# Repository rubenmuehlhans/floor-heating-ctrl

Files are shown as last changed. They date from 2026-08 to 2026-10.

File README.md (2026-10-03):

# Heizungssteuerung

Mehrere ESP32 im Haus, die zusammen eine Ölheizung überwachen und in Teilen
steuern. Jedes Gerät hat eine eigene Aufgabe, kennt die anderen über mDNS und
fragt bei ihnen ab, was es selbst nicht messen kann.

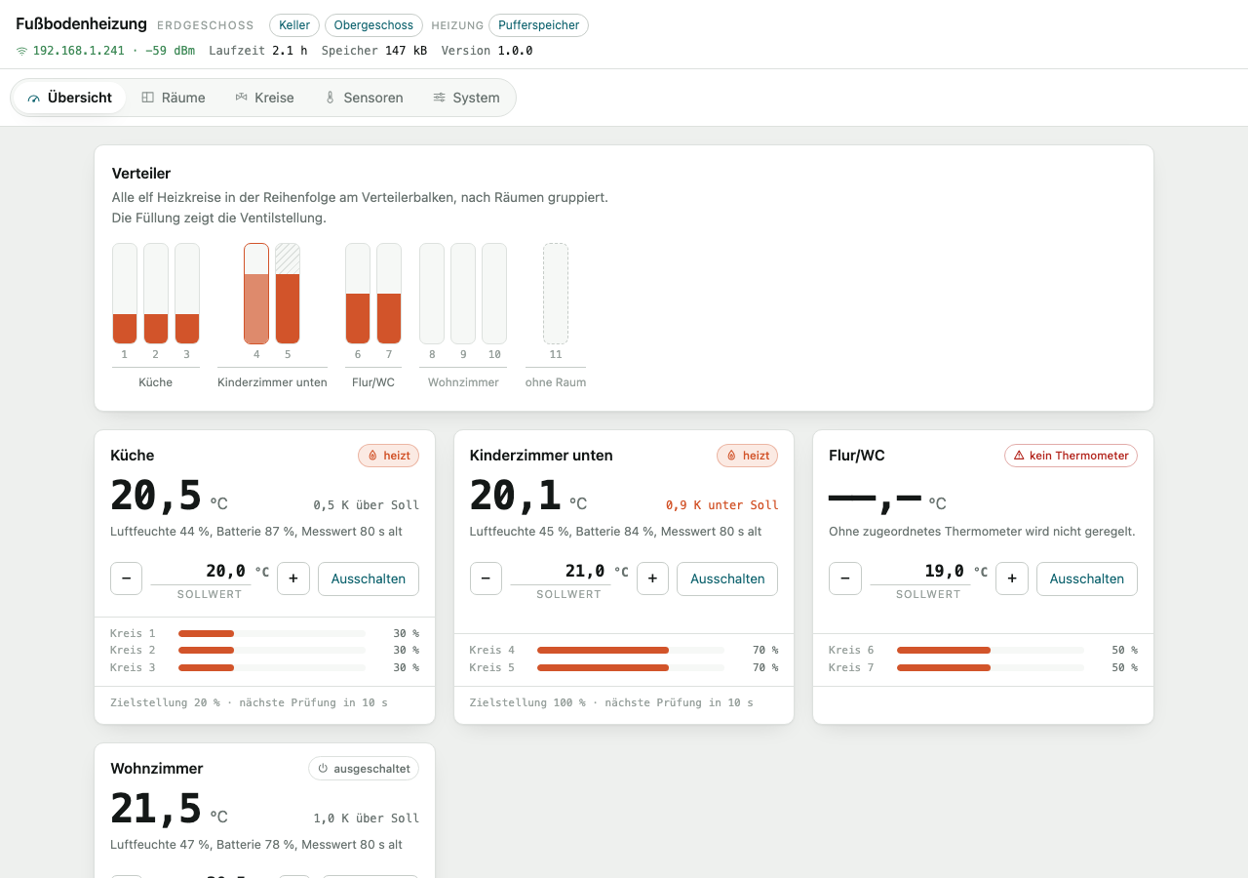
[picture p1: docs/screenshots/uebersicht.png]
Übersicht der Weboberfläche


## Was die Geräte tun

**Verteilerplatine**, je Etage eine. Sie fährt elf motorische Stellantriebe am
Heizkreisverteiler und regelt darüber die Raumtemperaturen. Die Antriebe haben
keine Endschalter; erkannt wird die Endlage an der Gegenspannung des
blockierenden Motors. Die Raumtemperaturen kommen über Bluetooth von
Xiaomi-Thermometern, die Außentemperatur von einem RuuviTag. Bedient wird über die Weboberfläche oder über Anzeige und
drei Tasten am Gehäuse. Einmal in der Woche fährt jeder Kreis einmal durch,
damit er über den Sommer nicht festsitzt. Wärmebedarf meldet sie nur für Räume,
die sie tatsächlich regelt; Kreise ohne Raum fährt sie zu.

**Gerät am Kessel.** Es misst Abgas, Kesselvorlauf und Kesselrücklauf. Am
Abgasfühler erkennt es, ob der Brenner läuft: Angelaufen ist er, wenn das Abgas
deutlich über einer gleitenden Bezugslinie liegt und um einen festen Ausschlag
über seinen letzten Tiefstwert gestiegen ist; aus ist er, wenn es um denselben
Ausschlag unter den Höchstwert der Fahrt fällt. Der Ausschlag greift auch bei
warmem Kessel, bei dem die Bezugslinie nicht mehr unterscheidet. Daraus
führt es Laufzeit, Startzahl und eine Verbrauchsschätzung. Es schaltet die
Kesselkreispumpe: Solange der Brenner läuft, läuft sie; danach entscheidet der
Abstand zwischen Kesselvorlauf und Speicher. Sie läuft, solange der Kessel
Wärme abgibt, und steht, sobald sie nur noch Wärme aus dem Speicher in den
Kessel tragen würde.

**Gerät am Pufferspeicher.** Es misst die Speichertemperatur und Vor- und
Rücklauf der Heizkreise, beurteilt daraus Ladezustand und Füllstand — dessen
Nullpunkt wird bei jedem Brennerstart nachgemessen — und schaltet die
Umwälzpumpen über Tasmota-Relais — ab, wenn kein Raum Wärme abruft, und
wöchentlich kurz an, damit sie nicht festsitzen. Ob ein Abnehmer da ist, fragt
es bei den Verteilerplatinen ab; den Brennerzustand holt es sich vom Gerät am
Kessel.

**Leitstand**, wahlweise. Ein M5Stack Core mit eigener Firmware
([`apps/station`](apps/station/)) zeigt den Zustand der Anlage auf seinem
Bildschirm, empfängt Funkthermometer und liefert die Außentemperatur an die
Heizungsgeräte; diese fragen ihn zuerst und erst danach die Verteilerplatinen.
Er regelt nichts. Aufzeichnung auf SD-Karte und HomeKit sind geplant, siehe
[Konzept Leitstand](docs/konzept-leitstand.md).

Welche Aufgabe ein Heizungsgerät übernimmt, ergibt sich allein aus den
zugeordneten Fühlerrollen. Beide Aufgaben sind dabei an eigene Messwerte
gebunden, nicht an solche aus dem Netz: Heizkreise lassen sich nur auf dem Gerät
mit dem Pufferfühler anlegen, die Kesselkreispumpe nur auf dem mit Kesselvor-
und -rücklauf. Mit fremden Werten zu schalten hieße, bei einem
Verbindungsabbruch ohne Grundlage dazustehen.

Kein Gerät ist auf ein anderes angewiesen. Fällt eines aus, arbeiten die
übrigen mit dem weiter, was sie selbst messen — die Pumpen laufen dann im
Zweifel, statt zu stehen.

**Aus dem laufenden Betrieb** entstehen zwei knappe Protokolle im Flash: je
abgeschlossener Ladung ein Satz, je Tag ein Satz. Daraus rechnet das Gerät zwei
Kennzahlen, die man sonst schätzt — den Wärmebedarf des Hauses je Heizgradtag
und den Grundverbrauch für Warmwasser — und meldet einen Tag, der deutlich über
dieser Linie liegt. Der Abstand zwischen Abgas- und Kesselvorlaufhöchstwert je
Ladung zeigt, ob der Wärmetauscher verrußt. Dazu kommen Plausibilitätsprüfungen
der Fühler, die Erkennung von Warmwasser, das bei stehender Pumpe in den
Kesselrücklauf strömt, und die Zählung der Warmwasserzapfungen. Alle Verfahren
melden, sie greifen nicht ein.

## Was daraus entsteht

Jedes Gerät bringt seine eigene Weboberfläche mit; eingerichtet wird alles
dort, ohne Übersetzen und ohne Konfigurationsdatei. An Home Assistant sind die
Geräte auf zwei Wegen anzubinden, einzeln oder gemeinsam: über MQTT-Discovery
oder über eine mitgelieferte Integration, die sie unmittelbar über HTTP
anspricht.

Der Quelltextbestand enthält neben der Firmware die Fertigungsdaten der Platine
([`board/`](board/)) und die Konstruktion des Gehäuses ([`case/`](case/)).

## Einordnung

Dies ist ein privates Bastelprojekt für die eigene Heizungsanlage. Es entsteht
in der Freizeit; eine laufende Betreuung, Unterstützung bei der Nachnutzung
oder Bearbeitung von Anfragen wird nicht zugesagt.

Das Projekt steht in keiner Verbindung zu einem Hersteller und implementiert
kein Funkprotokoll: Die Antriebe werden über eigene H-Brücken elektrisch
angesteuert, also durch Anlegen der Motorspannung. Verwendete
Produktbezeichnungen dienen allein der Angabe, welche Bauteile verbaut sind.

## Herkunft

Der Grundgedanke der Schaltung — Endlagenerkennung über die Gegenspannung,
Kanalauswahl über Schieberegister — und das Regelgesetz in
[`components/roomctrl`](components/roomctrl/) gehen auf
[floor-heating-controller](https://github.com/nliaudat/floor-heating-controller)
von nliaudat zurück, veröffentlicht unter der GPL-3.0. Dieser Bestand folgt ihr
darin; siehe [Lizenz](#lizenz).

## Inhalt

- [Was die Geräte tun](#was-die-geräte-tun)
- [Herkunft](#herkunft)
- [Dokumentation](#dokumentation)
- [Voraussetzungen](#voraussetzungen)
- [Hardware](#hardware)
- [Übersetzen und Einspielen](#übersetzen-und-einspielen)
- [Erste Inbetriebnahme](#erste-inbetriebnahme)
- [Weboberfläche](#weboberfläche)
- [Home Assistant](#home-assistant)
- [Funktionsweise](#funktionsweise)
- [Vorgabewerte](#vorgabewerte)
- [Fehlersuche](#fehlersuche)
- [Aufbau des Quelltextbestands](#aufbau-des-quelltextbestands)
- [Entwicklung ohne Hardware](#entwicklung-ohne-hardware)
- [Prüfungen](#prüfungen)
- [Stand der Erprobung](#stand-der-erprobung)
- [Offene Punkte](#offene-punkte)
- [Geplante Erweiterungen](#geplante-erweiterungen)
- [Fremdkomponenten](#fremdkomponenten)
- [Lizenz](#lizenz)
- [Marken](#marken)

## Dokumentation

| Dokument | Inhalt |
|---|---|
| [Benutzerhandbuch](docs/handbuch.md) | Bedienung, Einrichtung, Wartung und Fehlersuche — mit Aufnahmen beider Oberflächen |
| [Konzept: Wärmeerzeugung und Pumpensteuerung](docs/konzept-waermeerzeuger.md) | Messstellen, Brennererkennung, Ladezustand, Pumpenlogik |
| [Umbau auf zwei Anwendungen](docs/umbau-projektstruktur.md) | Aufteilung des Projekts und gemeinsame Komponenten |
| [Konzept: Auswertung der Anlage](docs/konzept-auswertung.md) | Anomalien und Wirkungsgrad aus den erfassten Daten — Datengrundlage, Verfahren, Reihenfolge |
| [Änderungen](CHANGELOG.md) | was sich seit welcher Fassung geändert hat |

Diese Seite beschreibt Hardware, Aufbau und Funktionsweise. Wer die Geräte bedienen
oder einrichten will, findet das im [Handbuch](docs/handbuch.md).

## Voraussetzungen

- **Verteilerplatine.** Benötigt werden die Steuerplatine aus [`board/`](board/)
  und ein darauf gesteckter ESP32-DevKitC mit WROOM-32, dazu bis zu elf
  motorische Stellantriebe ohne Endschalter am Heizkreisverteiler.
- **Raumtemperatur.** Je Raum wird ein Xiaomi-Thermometer mit ATC- oder
  pvvx-Firmware benötigt, das seine Messwerte als Rundruf sendet.
- **Außentemperatur.** Wahlweise ein RuuviTag; er wird an einer
  Verteilerplatine zugeordnet und liefert zusätzlich Feuchte und Luftdruck.
- **Heizungsgeräte.** Für Kessel und Pufferspeicher genügt je ein
  ESP32-DevKitC ohne eigene Platine, dazu DS18B20 am 1-Wire-Bus. Zum Schalten
  der Pumpen kommen Tasmota-Relais hinzu.
- **Netz.** Alle Geräte brauchen ein WLAN-Netz. Ein MQTT-Broker ist möglich,
  aber nicht nötig: Die Geräte finden einander über mDNS, und Home Assistant
  lässt sich auch über die mitgelieferte Integration anbinden.
- **Entwicklungsumgebung.** Zum Übersetzen wird ESP-IDF v6.0.2 vorausgesetzt.
- **Arbeiten ohne Gerät.** Die Geräteattrappe benötigt Python 3, die
  Erzeugung der Aufnahmen zusätzlich Google Chrome und ImageMagick.

## Hardware

Dieser Abschnitt beschreibt die **Verteilerplatine**. Die Geräte an Kessel und
Pufferspeicher brauchen keine eigene Platine: dort genügt ein ESP32-DevKitC mit
DS18B20 am 1-Wire-Bus, ein Anschlusswiderstand nach 3,3 V und, am
Pufferspeicher, je Heizkreis ein Tasmota-Relais für die Umwälzpumpe. Welcher
Anschluss sich für den Bus eignet, steht im
[Handbuch](docs/handbuch.md#anschluss-des-busses).

Verbaut sind motorische Stellantriebe vom Typ **HmIP-VDMOT**. Sie haben keine
Endschalter; die Endlage ist daran zu erkennen, dass der Motor am Anschlag
blockiert und die Spannung über dem Messwiderstand deutlich steigt.

Die Steuerplatine ist in EasyEDA selbst entworfen, von Hand geroutet und bei
**JLCPCB** gefertigt. Sie trägt
keinen eigenen Mikrocontroller: Ein **ESP32-DevKitC** wird auf Buchsenleisten
gesteckt und lässt sich damit ohne Löten tauschen. Fertigungsdaten, Gerber und
Stückliste liegen in [`board/`](board/), das Druckgehäuse in
[`case/`](case/).

| Baugruppe | Umsetzung |
|---|---|
| Stellantriebe | 11 × motorisch, ohne Endschalter (HmIP-VDMOT) |
| Anschluss der Antriebe | 11 × 4P4C-Buchse (RJ11) an der Platinenkante |
| Ansteuerung | 11 × L9110s H-Brücke, bidirektional |
| Auswahl des Kreises | 3 × SN74HC595 Schieberegister über SPI2, 22 der 24 Ausgänge belegt |
| Endlagenerkennung | Messwiderstand je Messgruppe an ADC1, 6 Messgruppen, Dämpfung 6 dB |
| Anzeige | SSD1327, 128 × 128, 16 Graustufen, I²C |
| Bedienung am Gerät | 3 kapazitive Tasten: Sollwert −, Sollwert +, Raumwahl |
| Vorlauffühler | DS18B20 am 1-Wire-Bus, bis zu 8 Fühler, eigene 4P4C-Buchse |
| Schaltschrank-Klima | HDC1080, I²C |
| Stromversorgung | HLK-5M03, Netzanschluss über Klemme auf der Platine |
| Rechner | ESP32-DevKitC (WROOM-32) auf Sockel |

> Auf der Platine liegt Netzspannung. Der Netzbereich ist durch gefräste
> Trennschlitze abgegrenzt; Aufbau und Gehäuse sind in
> [`case/README.md`](case/README.md) beschrieben, einschließlich der dort
> genannten Einschränkungen zu Werkstoff und Zugentlastung.

### Anschlussbelegung

| Funktion | Pin |
|---|---|
| Schieberegister | DATA 16, CLK 5, LATCH 17, OE 18 |
| Gegenspannung, ADC1, Dämpfung 6 dB | 36, 39, 34, 35, 32, 33 |
| 1-Wire | 23 |
| I²C | SDA 21, SCL 22 |
| Tasten | 4 (−), 2 (+), 15 (Raumwahl) |

Die Zuordnung steht ausschließlich in
[`components/hw_map/`](components/hw_map/); alles andere arbeitet mit
Kreisnummern 1 bis 11 und Gruppennummern 0 bis 5.

### Messgruppen

Je zwei Heizkreise teilen sich einen Messeingang:

| Gruppe | ADC-Pin | Kreise |
|---|---|---|
| 1 | 36 | 1, 2 |
| 2 | 39 | 3, 4 |
| 3 | 34 | 5, 6 |
| 4 | 35 | 7, 8 |
| 5 | 32 | 9, 10 |
| 6 | 33 | 11 |

Daraus folgt die zentrale Betriebsregel: **Innerhalb einer Messgruppe fährt
immer nur ein Kreis.** Sonst liegt die Gegenspannung beider Motoren auf
demselben Eingang und die Endlage ließe sich keinem Antrieb mehr zuordnen.
Durchgesetzt wird das von der Gruppensperre in
[`apps/manifold/main/app_control.c`](apps/manifold/main/app_control.c).

## Übersetzen und Einspielen

Fertige Abbilder liegen bei den [Veröffentlichungen](https://github.com/rubenmuehlhans/floor-heating-ctrl/releases).
Wer nicht selbst übersetzen will, spielt sie über USB unmittelbar aus dem
Browser auf: **[Web-Flasher](https://rubenmuehlhans.github.io/floor-heating-ctrl/)**
(Chrome oder Edge; die Web-Serial-Schnittstelle gibt es in Firefox und Safari
nicht). Die Seite liegt im Zweig `gh-pages` und lädt nichts von fremden
Rechnern nach.

Zum Selbstübersetzen: Vorausgesetzt wird ESP-IDF v6.0.2. Das Repositorium enthält mehrere
Anwendungen, die sich `components/` teilen; gebaut wird deshalb mit `-C` aus
dem Verzeichnis der jeweiligen Anwendung. Die Verteiler-Firmware liegt unter
`apps/manifold`. Der Leitstand (`apps/station`) braucht zusätzlich das esp-homekit-sdk, das als
Untermodul unter `third_party/` eingebunden ist; nach dem Klonen einmal
`git submodule update --init`.

```bash
. ~/esp/esp-idf-6.0.2/export.sh && idf.py -C apps/manifold set-target esp32 && idf.py -C apps/manifold build
```

```bash
idf.py -C apps/manifold -p /dev/cu.usbserial-0001 flash monitor
```

Spätere Aktualisierungen laufen über die Weboberfläche (System → Firmware
aktualisieren) oder direkt:

```bash
curl -X POST --data-binary @apps/manifold/build/floor-heating-ctrl.bin http://<adresse>/api/ota
```

Die Firmware belegt rund 1,2 MB. Die Partitionstabelle sieht zwei
OTA-Bereiche zu je 1 966 080 Byte vor; rund 39 % bleiben frei. Eine frisch
eingespielte Firmware wird erst bestätigt, wenn Konfiguration, Ausgangsstufe,
Regelung und Weboberfläche angelaufen sind; andernfalls kehrt der Bootlader zur
vorherigen zurück.

## Erste Inbetriebnahme

1. Nach dem ersten Einspielen findet das Gerät kein WLAN und öffnet sofort
   einen Zugangspunkt `floor-heating-XXXX` mit dem Kennwort `fussboden`. Die
   vier Stellen sind die letzten beiden Bytes der MAC-Adresse.
2. Beim Verbinden öffnet sich das Einrichtungsportal von selbst (Captive
   Portal). Rufen Sie andernfalls `http://192.168.4.1` auf.
3. Wählen Sie das Netz aus, tragen Sie das Kennwort ein und speichern Sie. Der
   Zugangspunkt schließt sich, sobald die Verbindung steht und niemand mehr
   daran hängt.
4. Danach führt der Einrichtungsassistent in drei Schritten durch die Anlage:
   Bezeichnung der Etage, Räume mit ihren Heizkreisen, Thermometer je Raum. Er
   startet von selbst, solange keine Bezeichnung hinterlegt ist, und ist später
   über **System → Einrichtung erneut durchlaufen** wieder erreichbar. Die
   Thermometer erscheinen zur Auswahl, sobald ihr erster Rundruf empfangen
   wurde.
5. Starten Sie unter **Kreise** für jeden Kreis eine Messfahrt.
6. Lesen Sie unter **Sensoren** die Rohwerte der Tasten in Ruhe und bei
   Berührung ab und setzen Sie die Schwelle etwa mittig.
7. Tragen Sie unter **System** die MQTT-Verbindung ein, falls Home Assistant
   angebunden werden soll; ab Werk ist MQTT ausgeschaltet.

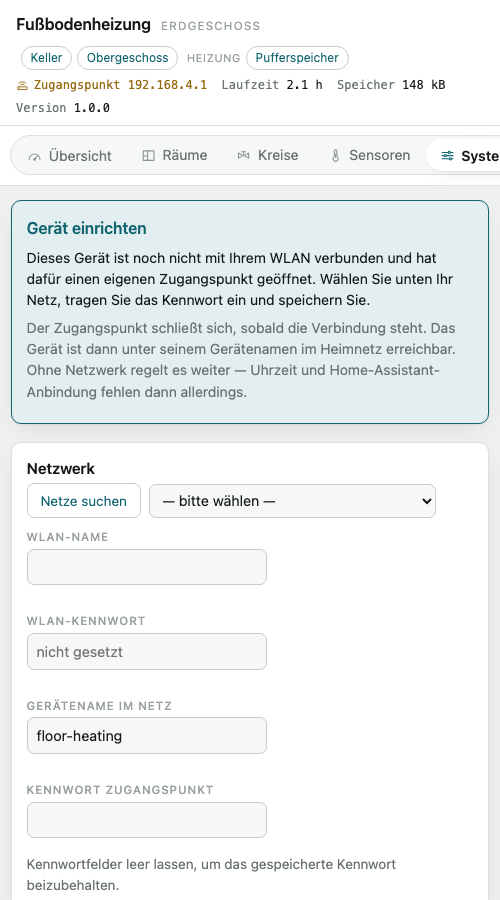
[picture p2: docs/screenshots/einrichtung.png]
Einrichtungsportal


## Weboberfläche

Räume, Kreiszuordnung, Thermometer und Regelparameter sind zur Laufzeit
änderbar. Die Weboberfläche liegt komprimiert im Programmabbild (rund 22 kB)
und lädt ohne Internetzugang.

| | |
|---|---|
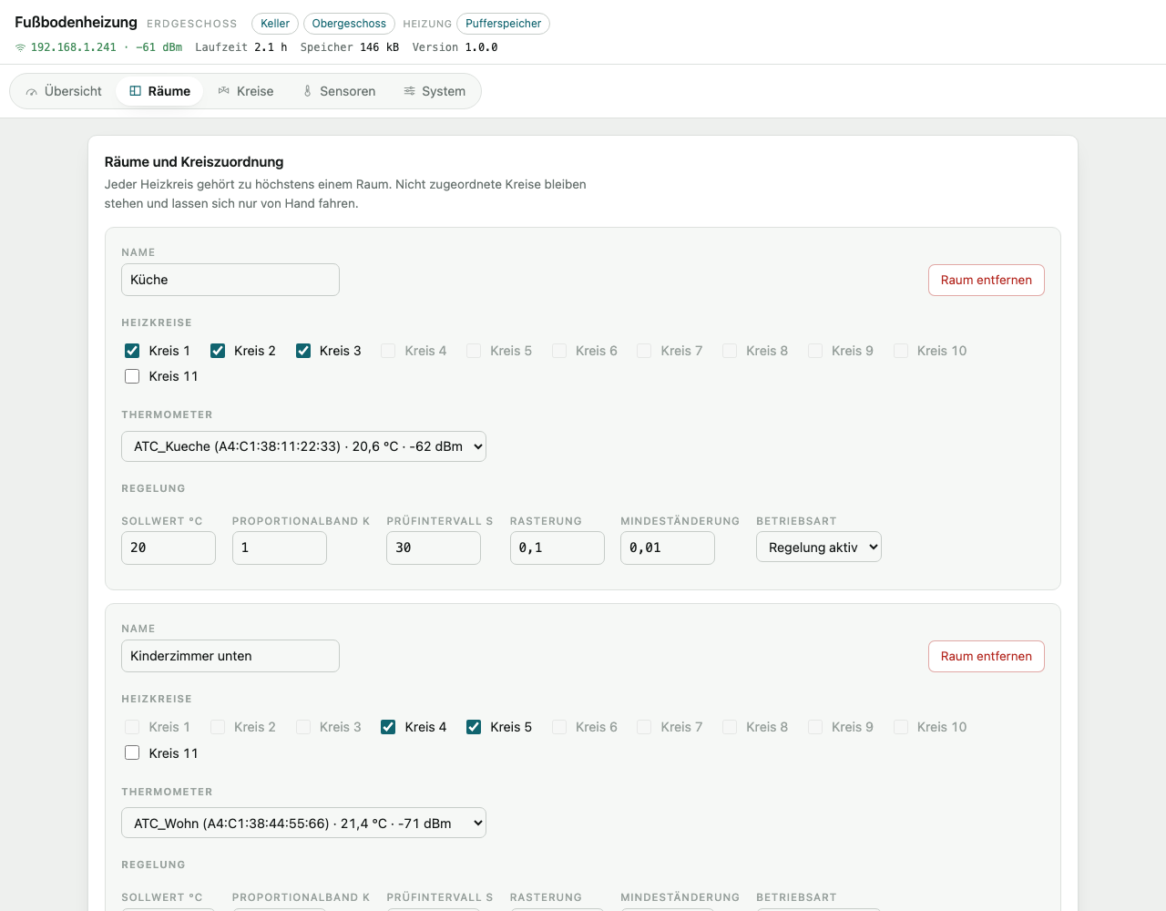
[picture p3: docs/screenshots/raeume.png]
Räume
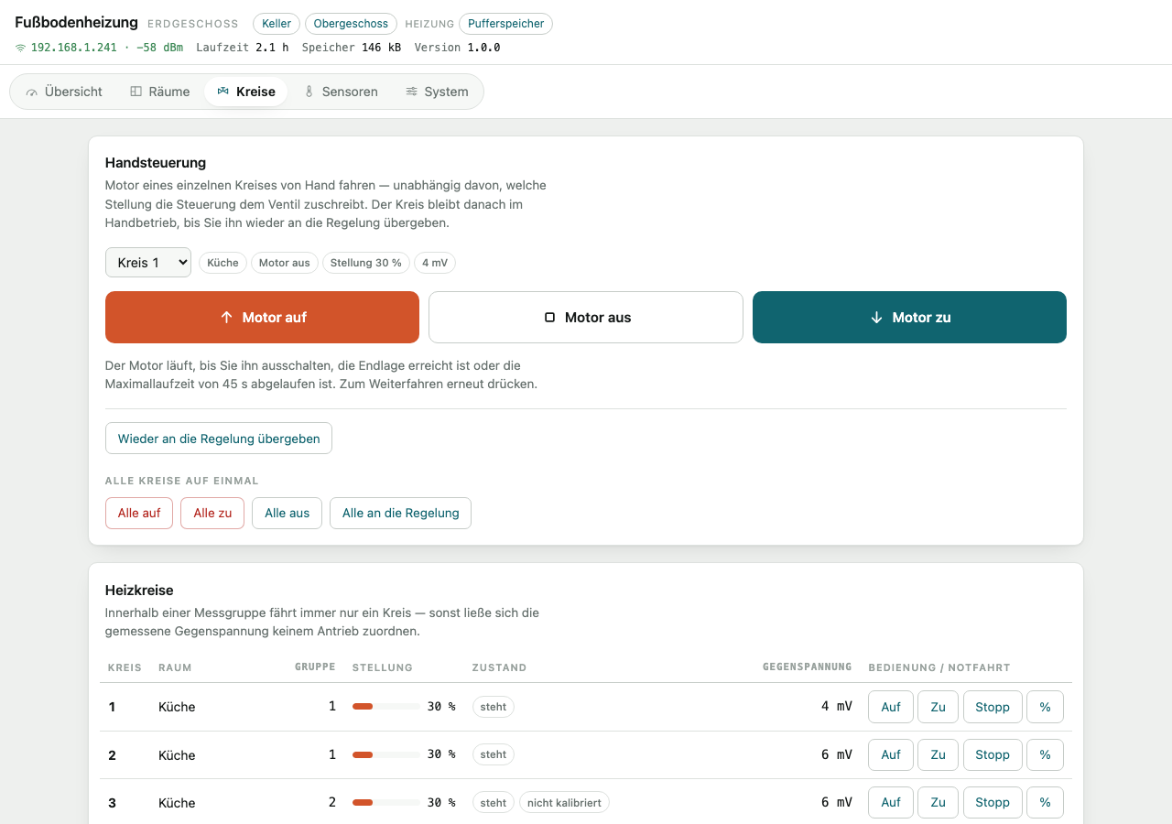
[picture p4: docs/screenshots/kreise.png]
Heizkreise
|  |  |
| **Räume** — Kreise zuordnen, Thermometer wählen, Regelparameter einstellen | **Kreise** — Zustand, Handsteuerung, Fahrzeiten und Schwellen |
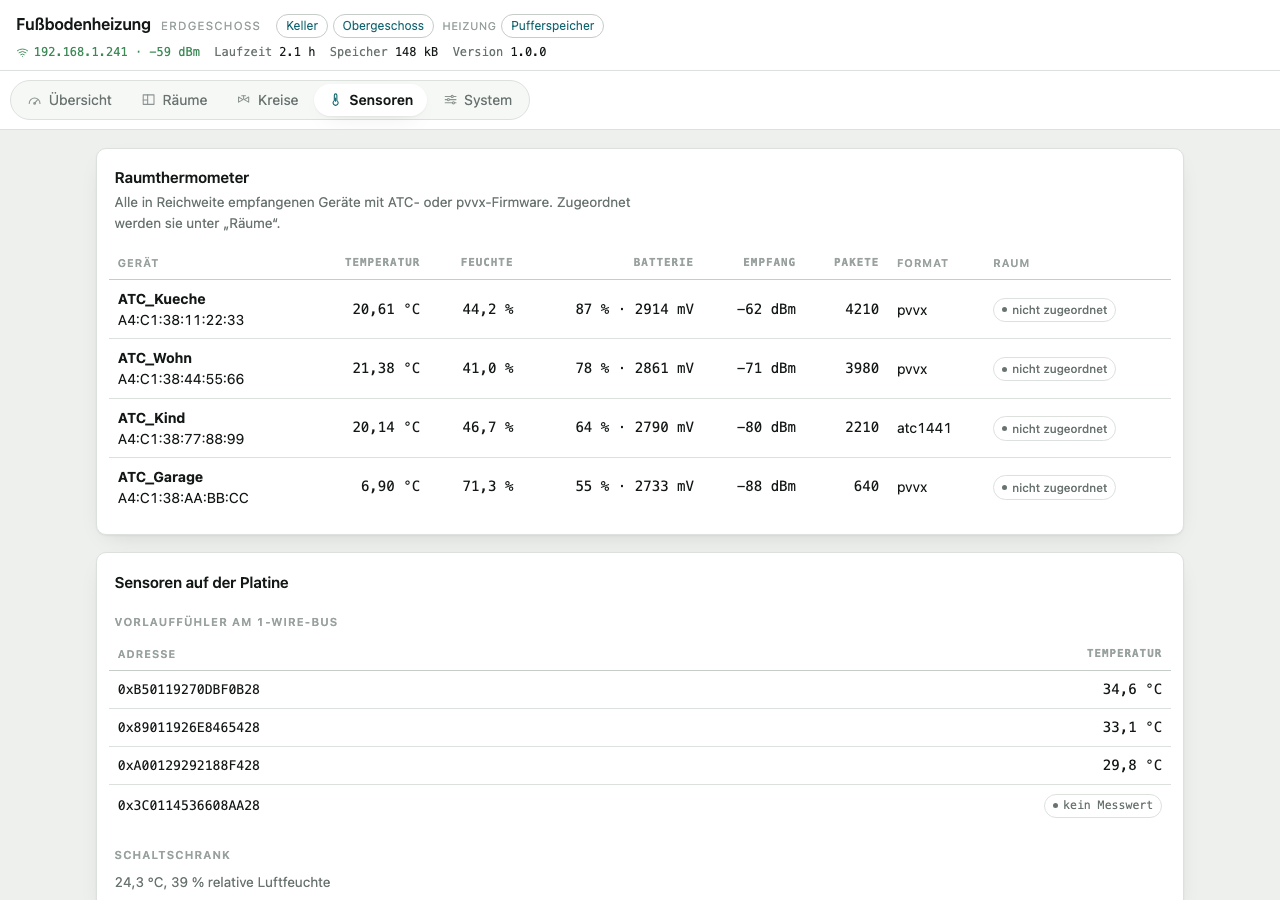
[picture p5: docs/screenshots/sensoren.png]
Sensoren
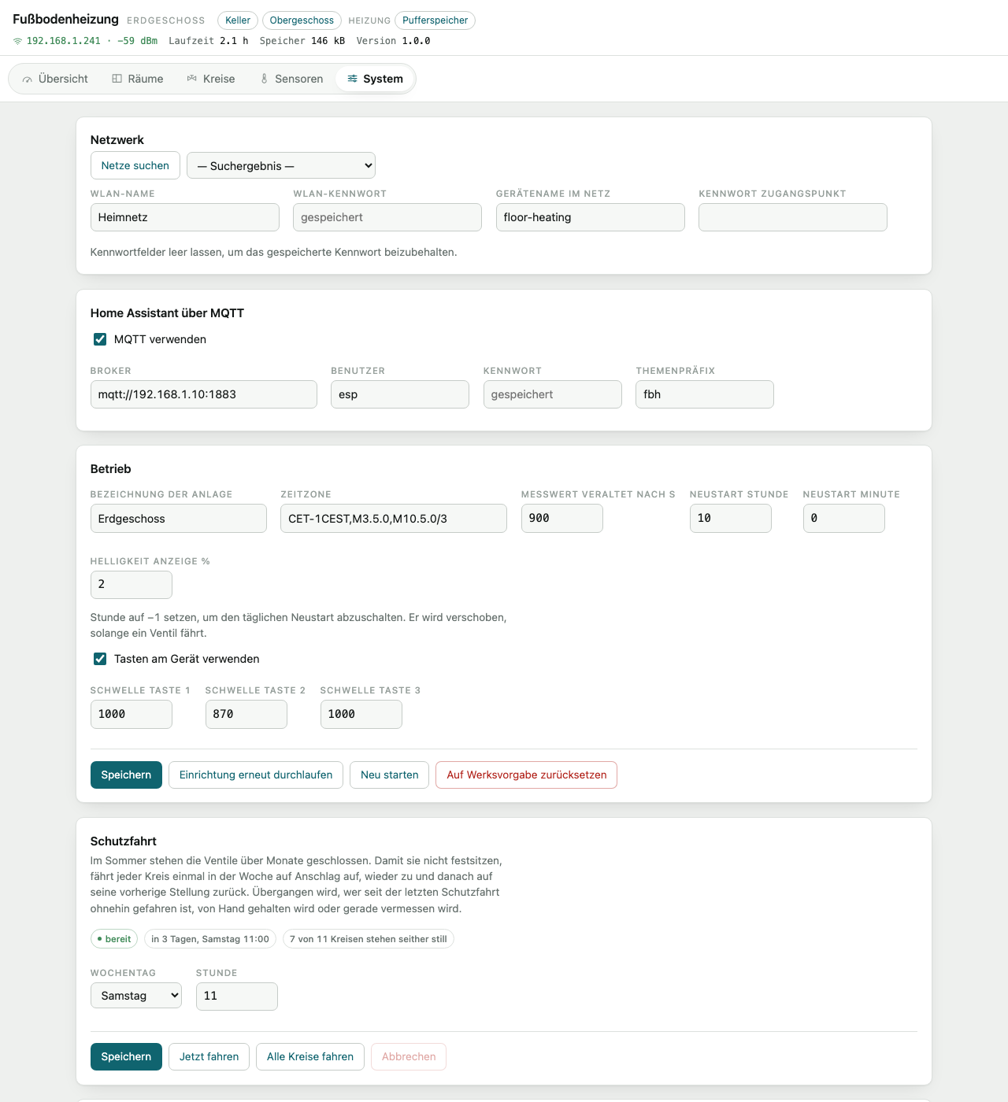
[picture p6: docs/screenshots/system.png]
System
|  |  |
| **Sensoren** — empfangene Thermometer, Vorlauffühler, Tastenabgleich | **System** — Netzwerk, MQTT, Betrieb, Firmware |

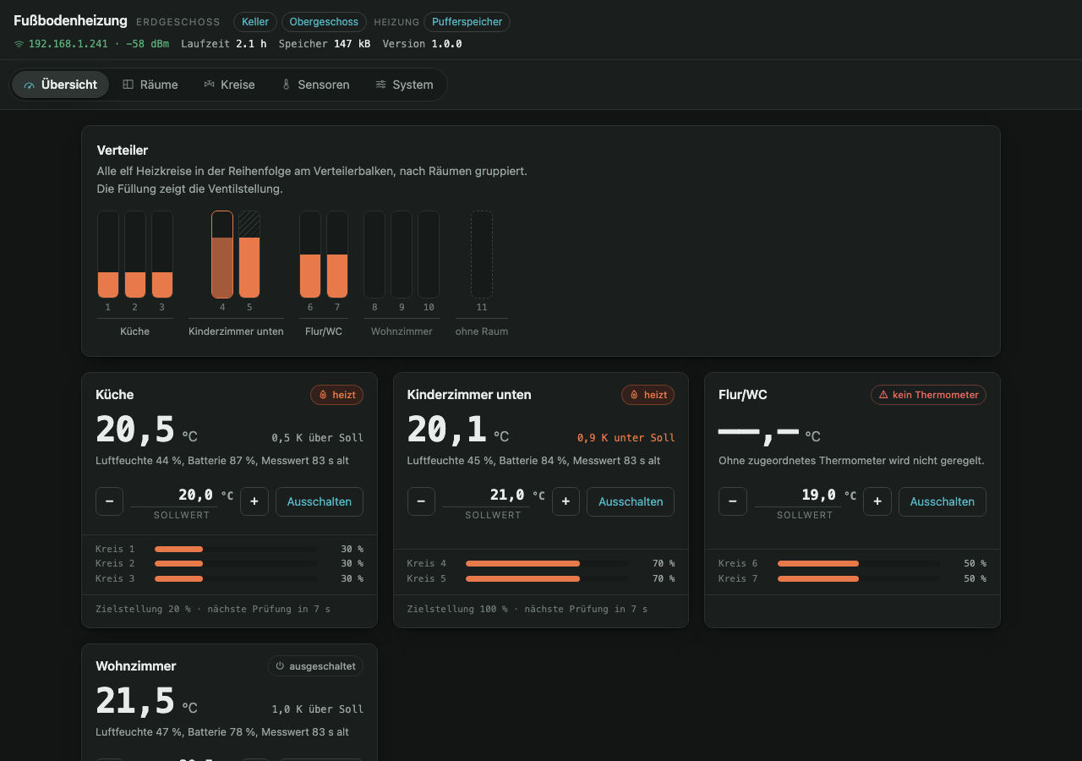
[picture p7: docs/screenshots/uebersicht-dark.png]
Dunkles Farbschema

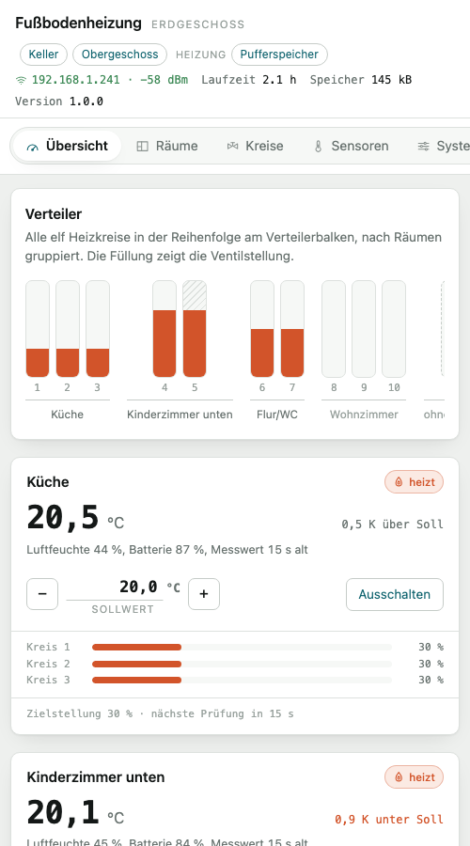
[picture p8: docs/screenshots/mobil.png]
Ansicht auf dem Telefon


### Abfragetakt

Die Seite fragt den Gerätezustand nicht in festem Takt ab, sondern richtet sich
danach, was sich tatsächlich ändert:

| Lage | Takt |
|---|---|
| ein Ventil fährt oder eine Messfahrt läuft | 1 s |
| Ruhezustand | 6 s |
| Seite im Hintergrund | keine Abfrage |
| Messreihe während einer Messfahrt | 400 ms |
| Liste der empfangenen Thermometer | 30 s |

`/api/state` gibt den Änderungszähler als ETag mit. Fragt die Seite mit
demselben Wert erneut an und fährt gerade kein Ventil, antwortet das Gerät mit
304 und erspart sich den Aufbau der rund 4 kB großen Antwort. Restzeiten,
Messwertalter und Laufzeit rechnet die Seite selbst weiter.

Fährt ein Kreis 20 % der Zeit, ergibt das rund 20 Zustandsabfragen je Minute;
Inhalt liefern davon nur die während der Fahrt und die nach einer Änderung.

## Home Assistant

Es gibt zwei Wege. Beide führen zu denselben Entitäten; sie schließen einander
nicht aus, sollten aber nicht gleichzeitig verwendet werden, weil sonst zwei
Wege dieselben Werte setzen.

### Eigene Integration

Unter [`custom_components/floor_heating/`](custom_components/floor_heating/)
liegt eine Integration, die unmittelbar mit dem Gerät spricht. Sie braucht
keinen MQTT-Broker und wird über HACS als benutzerdefiniertes Repository
hinzugefügt oder von Hand nach `config/custom_components/` kopiert. Eingerichtet
wird sie über **Einstellungen → Geräte & Dienste → Integration hinzufügen**;
gefragt wird nur nach der Adresse des Geräts.

Zusätzlich zu den Entitäten stellt sie fünf Dienste bereit, die sich in
Automatisierungen aufrufen lassen:

| Dienst | Wirkung |
|---|---|
| `floor_heating.calibrate` | Messfahrt für einen Kreis starten |
| `floor_heating.calibrate_accept` | Ergebnis der Messfahrt übernehmen |
| `floor_heating.calibrate_abort` | laufende Messfahrt abbrechen |
| `floor_heating.force` | Notfahrt auf, zu oder anhalten |
| `floor_heating.release` | Handbetrieb eines Kreises aufheben |

Der Zustand wird alle fünf Sekunden abgefragt. Da das Gerät seinen
Änderungszähler als ETag mitgibt, bleibt die Abfrage im Ruhezustand ohne
Inhalt (siehe [Abfragetakt](#abfragetakt)).

Ob Schnittstelle und Integration zueinander passen, prüft
`tools/check_api.py` ohne laufende Home-Assistant-Installation:

```bash
python3 tools/check_api.py 192.168.1.250
```

### MQTT-Discovery

Die Entitäten werden per MQTT-Discovery angemeldet und bei jeder
Konfigurationsänderung neu berechnet; entfallene Räume werden wieder entfernt.

| Typ | Umfang |
|---|---|
| `cover` | 11 Heizkreise mit Position, Öffnen/Schließen/Stopp |
| `climate` | je eingerichtetem Raum |
| `sensor`, je Raum | Temperatur, Luftfeuchte, Batterie des Thermometers, Zielstellung |
| `sensor`, Diagnose | 6 Messgruppen in mV, erkannte Vorlauffühler, Schaltschrankklima, Laufzeit, WLAN-Empfang, freier Speicher |
| `button` | Neustart, Regelung je Raum sofort auslösen |

Öffnen, Schließen und Stopp über die `cover`-Entitäten setzen den Halt des
Handbetriebs und bleiben damit stehen; eine gesetzte Position tut das nicht und
wird von der Regelung wieder überschrieben.

Die 22 einzelnen H-Brücken-Eingänge werden bewusst **nicht** exportiert, denn
direktes Schalten umginge Verriegelung und Gruppensperre.

## Funktionsweise

Dieser Abschnitt beschreibt die Verteilerplatine. Wie Brennererkennung,
Ladezustand und Pumpensteuerung arbeiten, steht im
[Konzept zur Wärmeerzeugung](docs/konzept-waermeerzeuger.md).

### Endlagenerkennung

Im Lauf zieht der Motor eine kleine Spannung über den Messwiderstand; erreicht
das Ventil den Anschlag, blockiert er und die Spannung steigt deutlich. Alle
sechs Messgruppen werden alle 50 ms abgetastet, ausgewertet wird ein gleitender
Median über fünf Werte. Erreicht er die Auslöseschwelle, gilt die Endlage als
erreicht und die Position wird auf 0 beziehungsweise 100 % gesetzt. Scharf ist
die Auswertung nur für die Messgruppe eines gerade fahrenden Kreises; die
Schwelle ist dann die des fahrenden Kreises.

Nach dem Anlauf gilt eine Sperrzeit von zwei Sekunden, in der die Meldung
verworfen wird, denn der Einschaltstrom sieht sonst wie ein Blockieren aus.
Bleibt die Endlage aus, beendet die Maximallaufzeit die Fahrt.

### Messfahrt zur Schwellwertermittlung

Die Auslöseschwelle hängt von Antrieb, Messwiderstand und Verkabelung ab.
Statt sie von Hand zu suchen, fährt die Messfahrt den Kreis einmal ganz zu und
einmal ganz auf und schreibt dabei den Spannungsverlauf mit. Das Blockieren
wird **relativ** zum gemessenen Fahrniveau erkannt; eine vorhandene Schwelle
geht nicht ein, sonst würde die Messfahrt ihr eigenes Ergebnis voraussetzen.

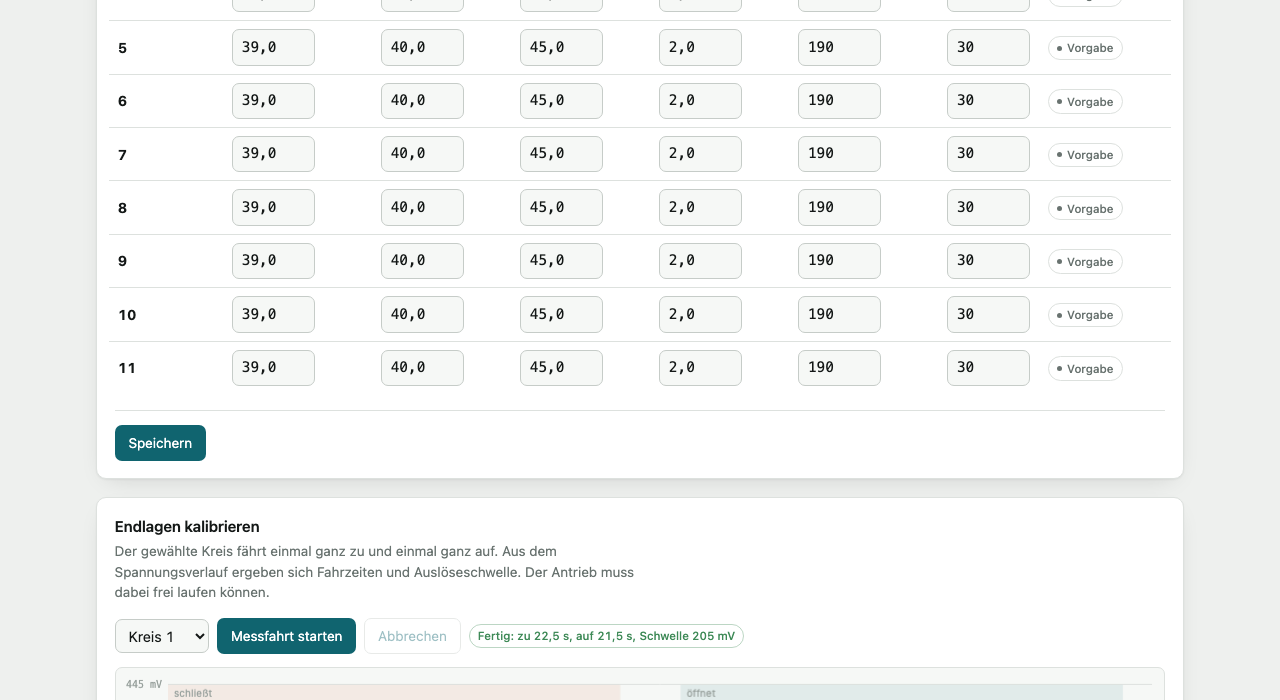
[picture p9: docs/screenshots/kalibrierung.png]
Ergebnis einer Messfahrt


Braun ist die Schließfahrt, blau die Öffnungsfahrt, dazwischen liegen drei
Sekunden Ruhe. Die beiden Spitzen sind die Anschläge. Aus dem Verlauf ergeben
sich Fahrzeiten, Maximallaufzeit (längste Fahrzeit plus rund 15 %),
Auslöseschwelle (Mitte zwischen Fahrniveau und niedrigerer Spitze) und
Hysterese; übernommen werden sie erst nach Bestätigung.

Wird in einer Fahrtrichtung keine Endlage erkannt, bricht die Messfahrt mit
einem Hinweis auf Verdrahtung und Messwiderstand ab.

### Handsteuerung und Notfahrt

Jeder Kreis lässt sich von Hand fahren, **unabhängig davon, welche Stellung
die Steuerung ihm zuschreibt**. Das ist kein gewöhnlicher Fahrbefehl:
`valve_goto` prüft die geschätzte Stellung und täte nichts, wenn das Ventil
bereits als offen gilt; bei unbekannter Stellung führe es sogar erst eine
Referenzfahrt gegen die untere Endlage aus, bei „auf“ also zunächst zu. Für
den Notfall ist beides falsch.

`valve_force` fährt deshalb ohne Stellungsvergleich bis zum Anschlag. Beendet
wird die Fahrt nur durch die Endlage, die Maximallaufzeit oder einen Halt. Über
`/api/channel/all/cmd` gilt der Befehl für alle elf Kreise zugleich.

Danach bleibt der Kreis im **Handbetrieb**: Die Regelung fasst ihn nicht mehr
an, bis er ausdrücklich wieder freigegeben wird. Ohne diesen Halt wäre eine
von Hand erzwungene Stellung beim nächsten Regeldurchlauf nach spätestens
einem Prüfintervall wieder verworfen. Denselben Halt setzt ein Stoppbefehl:
Von Hand angehalten bleibt von Hand angehalten. Die Freigabe erfolgt über den
Befehl „Automatik“, einzeln oder für alle Kreise; der zugehörige Raum wird
sofort neu bewertet, statt bis zum nächsten Prüfintervall zu warten.

Ein Fahrbefehl auf eine bestimmte Stellung setzt den Halt **nicht** — er wird
von der Regelung nach spätestens einem Prüfintervall überschrieben.

Die Gruppensperre gilt weiter: Fährt in derselben Messgruppe bereits ein
anderer Kreis, wartet der Befehl, bis sie frei ist.

### Regelung

Die Ventilstellung folgt der Regelabweichung proportional, über ein Band von
±1 K (Vorgabe) von ganz zu bis ganz auf, gerastert auf Zehntel:

```text
diff = soll − ist
pos  = runden(((diff / band) + 1) / 2 / raster) × raster,   begrenzt auf 0 … 1
gefahren wird, wenn |aktuell − pos| > Mindeständerung
```

Band, Rasterung, Mindeständerung und Prüfintervall sind je Raum einstellbar.
Der erste Regeldurchlauf findet erst 50 Sekunden nach dem Start statt, damit
Messwerte und Netzwerk eingelaufen sind. Die Ventilstellungen werden höchstens
einmal je Minute in den NVS geschrieben und beim Start wiederhergestellt.

### Raumtemperatur

Der ESP32 hört die Raumthermometer selbst mit: Xiaomi-Thermometer mit ATC- oder
pvvx-Firmware, RuuviTags und Thermometer mit BTHome senden ihre Messwerte als
Rundruf. Es wird keine Verbindung aufgebaut und nichts gesendet. Damit hängt die
Regelung nicht am Netzwerk. Verschlüsseltes BTHome, etwa vom Climate-Sat von
camperSense, liest der Verteiler mit dem Schlüssel des jeweiligen Geräts, den die
Oberfläche unter **Sensoren** entgegennimmt.

Bleibt ein Messwert länger als eingestellt aus (Vorgabe 900 s), setzt die
Regelung für diesen Raum aus und die Ventile bleiben stehen, statt mit einem
veralteten Wert weiterzuregeln. Dasselbe gilt, solange für einen Raum noch kein
Messwert eingegangen ist. Wärmebedarf meldet der Raum in dieser Zeit nicht.

## Vorgabewerte

Bis zur ersten Messfahrt und vor der Einrichtung gelten diese Werte. Sie
stammen aus dem Betrieb der Anlage. Die Tabelle gilt für die Verteilerplatine;
die Vorgaben der Heizungsgeräte und jede einzelne Einstellung beider Gerätetypen
mit ihrem zulässigen Bereich stehen im
[Handbuch](docs/handbuch.md#konfiguration-im-einzelnen).

| Größe | Vorgabe |
|---|---|
| Öffnungszeit / Schließzeit je Kreis | 39 s / 40 s |
| Maximallaufzeit je Kreis | 45 s |
| Auslöseschwelle / Hysterese | 190 mV / 30 mV |
| Sperrzeit nach dem Anlauf | 2 s |
| Solltemperatur je Raum | 20 °C |
| Proportionalband | 1,0 K |
| Rasterung / Mindeständerung | 0,1 / 0,01 |
| Prüfintervall | 30 s |
| Höchstalter eines Raummesswerts | 900 s |
| Täglicher Neustart | 10:00 Uhr, Zeitzone `CET-1CEST,M3.5.0,M10.5.0/3` |
| Gerätename | `floor-heating` |
| Kennwort des Einrichtungs-Zugangspunkts | `fussboden` |
| MQTT | ausgeschaltet, Präfix `fbh` |
| Tastenschwellen | 1000, 870, 1000 |

Ein täglicher Neustart wird verschoben, solange ein Stellantrieb fährt.

## Fehlersuche

Die folgenden Fälle ergeben sich aus dem beschriebenen Verhalten des Geräts.

| Beobachtung | Ursache | Abhilfe |
|---|---|---|
| Das Gerät verbindet sich nicht, ein Zugangspunkt `floor-heating-XXXX` erscheint | Es sind keine WLAN-Zugangsdaten hinterlegt | Über das Einrichtungsportal verbinden |
| Das Einrichtungsportal öffnet sich beim Verbinden nicht von selbst | Das Betriebssystem erkennt das Captive Portal nicht | `http://192.168.4.1` aufrufen |
| Ein Raum wird nicht geregelt, die Ventile stehen | Der Messwert ist älter als das eingestellte Höchstalter, oder es liegt noch keiner vor | Empfang unter **Sensoren** prüfen |
| Die Messfahrt bricht mit einem Hinweis ab | In einer Fahrtrichtung wurde keine Endlage erkannt | Verdrahtung und Messwiderstand prüfen |
| Ein Kreis folgt der Regelung nicht | Der Kreis steht im Handbetrieb | Befehl „Automatik“ für den Kreis oder für alle Kreise |
| Ein Fahrbefehl wird erst verzögert ausgeführt | In derselben Messgruppe fährt bereits ein anderer Kreis | Abwarten; die Gruppensperre gibt den Befehl frei |
| Die Tasten am Gehäuse lösen nicht aus | Die Tastenschwellen passen nicht zur Baugruppe | Rohwerte unter **Sensoren** ablesen, Schwelle mittig setzen |
| Nach einer Aktualisierung läuft wieder die vorherige Firmware | Die neue Fassung ist nicht vollständig angelaufen und wurde nicht bestätigt | Ursache über `idf.py monitor` suchen |

## Aufbau des Quelltextbestands

```text
apps/manifold/    Verteiler-Firmware
  main/
    main.c        Start der Bausteine
    app_control.c Ventilzustände, Gruppensperre, Raumregelung   ← Kern
    app_calib.c   Messfahrt und Auswertung der Schwellwerte
    app_web.c     HTTP-Server, JSON-Schnittstelle, Captive Portal, OTA
    app_mqtt.c    Home-Assistant-Discovery und Zustände
    app_ui.c      Anzeige und Tasten am Gerät
    www/            Oberfläche: kopf.html, rumpf.html und sources.txt
apps/heatsource/  Firmware der Heizungsgeräte (Kessel und Pufferspeicher)
  components/     eigene Konfiguration, verdrängt die gemeinsame
  main/           Fühlererfassung, Verlauf, Weboberfläche
www/stil.css      gemeinsames Gerüst beider Oberflächen: Farben, Schriften,
                  Kopfzeile, Reiter — die Bedienelemente bleiben je Anwendung eigen
cmake/embed_www   Bauregel: Oberfläche zusammenfügen, komprimieren, einbetten
components/       von allen Anwendungen gemeinsam genutzt
  hw_map/         Pin- und Gruppentabellen — einzige Stelle mit Hardwarewissen
  sr74hc595/      Schieberegister mit Verriegelung IA gegen IB
  valve/          Zustandsmaschine je Kreis (frei von IDF-Abhängigkeiten)
  bemf/           ADC-Abtastung, gleitender Median, Schwellwertauswertung
  roomctrl/       Regelgesetz (frei von IDF-Abhängigkeiten)
  schedule/       wöchentlicher Termin an der Uhr, für die Schutzfahrt
  config_store/   Konfiguration als JSON im NVS
  atc_ble/        NimBLE-Observer; die Dekoder (ATC, pvvx, Ruuvi, BTHome) und
                  AES-128-CCM liegen als atc_decode.c und atc_crypto.c ohne
                  IDF-Bezug daneben und sind geprüft
  ssd1327/        Anzeigetreiber mit Bitmap-Schrift
  sensors_local/  DS18B20 und HDC1080
  onewire_temp/   mehrere DS18B20 an bis zu zwei Bussen, Sammelwandlung
  netmgr/         WLAN, SNTP, täglicher Neustart
  captive_dns/    Namensdienst des Einrichtungsportals
  i2cbus/         gemeinsamer I²C-Bus
board/            Fertigungsdaten der Platine: Gerber, DXF, Stückliste (eigene
                  README und eigene Lizenz)
case/             Druckgehäuse, mit CadQuery konstruiert (eigene README)
test/host/        Prüfungen ohne IDF und ohne Hardware
tools/            Geräteattrappe, Bildschirmaufnahmen, Prüfung der Schnittstelle
custom_components/
                  Integration für Home Assistant (über HACS einzubinden)
docs/             Konzepte und Aufnahmen dieser Seite
```

## Entwicklung ohne Hardware

Die Weboberfläche lässt sich ohne Gerät bedienen. `tools/mock_device.py`
liefert die echte Seite mit erfundenen Messwerten aus:

```bash
python3 tools/mock_device.py
```

Rufen Sie danach `http://localhost:8321` auf. Der Parameter `?theme=dark`
erzwingt ein Farbschema, `#kreise` und die übrigen Anker öffnen einen Bereich
direkt. Mit `/mock/ap?on=1` schaltet die Attrappe in den Zugangspunkt-Betrieb,
sodass sich das Einrichtungsportal ansehen lässt. Aus diesen Ansichten erzeugt
`tools/screenshots.sh` die Aufnahmen dieser Seite; vorausgesetzt werden Google
Chrome und ImageMagick.

Mit `--app` liefert die Attrappe die Oberfläche einer anderen Anwendung aus;
der Port richtet sich dann nach der Anwendung, sofern `--port` nichts anderes
vorgibt. Für die Heizungsgeräte gibt es eine eigene Attrappe:

```bash
python3 tools/mock_heatsource.py
```

Sie bildet ein Speicherboard nach; mit `--kessel` stattdessen ein Kesselboard,
mit `--leer` ein Gerät ohne angeschlossene Fühler. Aufrufbar unter
`http://localhost:8322`.

Die Aufnahmen dieser Seite und des Handbuchs entstehen gegen die beiden Attrappen:

```bash
tools/screenshots.sh        # Verteilerplatine, gegen mock_device.py
tools/screenshots_heat.sh   # Heizungsgerät, gegen mock_heatsource.py
```

Beide Skripte prüfen nebenbei, dass die Oberfläche in beiden Farbschemata und in der
schmalen Ansicht steht. Vorausgesetzt werden Google Chrome und ImageMagick.

## Prüfungen

Regelgesetz, Ventil-Zustandsmaschine und Hardwarezuordnung laufen ohne IDF und
ohne Hardware:

```bash
make -C test/host
```

Der Lauf umfasst 611 Prüfungen, dazu 137 für das Protokoll des Leitstands: Regelgesetz, Ventil-Zustandsmaschine, Hardwarezuordnung,
Pumpensteuerung, Bedarfsauswertung, Brennererkennung, Ladezustand und Kalibrierung des
Nullpunkts, Auslöser der Aufzeichnung, Dekodierung und Entschlüsselung der Funkpakete
(AES-128 gegen FIPS-197, BTHome gegen Rahmen aus dem Rahmenbau der Satelliten-Firmware),
Wochentermin,
Plausibilität der Fühler, Rückströmung, Warmwasserzapfung, Kesselkreispumpe, Verbrauchslinie
und Abgas-Vorlauf-Abstand.

Dazu prüft

```bash
python3 tools/check_www.py
```

dass die eingebetteten Oberflächen übersetzbar sind — sie werden dafür aus ihren Teilen
zusammengesetzt, geprüft wird also das, was auch im Gerät landet — der Skriptteil wird mit `node --check`
geprüft. Anlass war, dass beim Bearbeiten zweimal ein Block an der falschen Stelle gelandet ist:
einmal JavaScript im Stilblatt, einmal CSS im Skript. Im Quelltext fällt das nicht auf, im
Browser bleibt die Seite leer.

Außerdem vergleicht

```bash
python3 tools/check_defaults.py
```

Vorgabewerte, die an zwei Stellen stehen: die der Einstellungsablage des Heizungsgeräts mit
denen der Rechenmodule unter `components/heatlogic`, und die Werte, mit denen die
Verteiler-Oberfläche einen neuen Raum anlegt, mit denen der Firmware. Die Rechenmodule werden
ohne Gerät geprüft, ein neues Gerät bezieht seine Einstellungen aber aus der Ablage — laufen die
beiden auseinander, gelten die Prüfungen für andere Werte als die im Betrieb. Anlass war die
Kesselkreispumpe: Das Modul schaltete bei 3,0 und 2,0 K, ein neu eingerichtetes Gerät hätte
1,0 und 0,5 K erhalten.

Gegen ein laufendes Gerät prüft

```bash
python3 tools/check_api.py 192.168.1.250
```

die Schnittstelle mit derselben Klasse, die auch die Home-Assistant-Integration benutzt. Beide
Gerätearten werden erkannt.

An der Hardware sind folgende Schritte vorgesehen:

1. **Schieberegister.** Schalten Sie alle 22 Ausgänge einzeln, messen Sie gegen
   die L9110s-Eingänge und prüfen Sie die Verriegelung: IA und IB dürfen nie
   gleichzeitig anliegen.
2. **Ventilfahrt.** Fahren Sie einen Kreis ganz zu und ganz auf und prüfen Sie
   Laufzeit und Abschaltung über die Endlage. Die Maximallaufzeit muss greifen,
   wenn die Endlage ausbleibt.
3. **Messfahrt.** Führen Sie eine Messfahrt eines Kreises durch und halten Sie
   den Verlauf gegen den Vorgabewert von 190 mV.
4. **Gruppensperre.** Lassen Sie Kreis 1 fahren und fordern Sie währenddessen
   Kreis 2 an; Kreis 2 darf erst danach fahren.
5. **Tasten.** Lesen Sie unter **Sensoren** die Rohwerte in Ruhe und bei
   Berührung ab und setzen Sie die Schwelle etwa mittig.
6. **MQTT.** Prüfen Sie, ob die Entitäten in Home Assistant erscheinen.
   Löschen Sie einen Raum und legen Sie ihn neu an; die Entitäten müssen
   verschwinden und wiederkommen.

## Stand der Erprobung

Stand 21. September 2026. Im Haus laufen fünf Geräte: Verteilerplatinen im Keller, im
Erdgeschoss und im Obergeschoss sowie je ein ESP32 an Kessel und Pufferspeicher.

**Verteilerplatinen.** Erprobt sind Start, BLE-Empfang der Thermometer,
Tastenauswertung, Weboberfläche, Captive Portal, Aktualisierung über das Netz,
Handsteuerung, Messfahrten und die wöchentliche Schutzfahrt — elf Kreise
in 168 s, sechs gleichzeitig, danach alle wieder auf ihrer vorherigen Stellung.
Bei der Schutzfahrt fiel auf, dass acht der elf Kreise mangels Messfahrt keine
Endlage erkennen und in die Maximallaufzeit laufen.

**Einrichtung einer neuen Platine.** Die Verbindung mit dem Einrichtungs-Zugangspunkt gelang
anfangs nur unzuverlässig, weil der Bluetooth-Empfang das gemeinsame Funkteil durchgehend
belegte. Er belegt es jetzt zu 30 Prozent und ruht, solange nur der Zugangspunkt läuft; die
Verbindung gelingt seitdem beim ersten Versuch.

**Kessel und Pufferspeicher.** Erprobt sind Fühlererfassung, gegenseitiges
Auffinden über mDNS und die Übernahme der Kesselwerte durch den Pufferspeicher:
Er zeigt Brennerzustand und Abgaswert des Nachbargeräts an und schaltet die
Aufzeichnung von selbst auf den Brennerzustand um, sobald der Kessel im Netz
ist. Nach einem Neustart dauert das rund achtzig Sekunden.

**Heizbetrieb.** Seit Mitte August zeichnen die Heizungsgeräte Ladungen auf, bis zum Stichtag
23. Die Brennererkennung ist an diesen Verläufen nachgestellt: Die ursprüngliche Regel — aus,
sobald sich das Abgas der Bezugslinie nähert — hielt den Brenner bei warmem Kessel vier Stunden
lang für an. Das Ende wird seitdem am Abfall gegen den Höchstwert der Fahrt erkannt. Eine Ladung
aus dem kalten Kessel galt anfangs nach wenigen Minuten als fertig, weil Vor- und Rücklauf beide
kalt waren und dicht beieinanderlagen; verlangt wird seitdem zusätzlich ein heißer Vorlauf.

**Kesselkreispumpe.** Die Ausschaltschwelle von 2 K stammt aus einer Messung: Der Speicher
erreichte seinen Höchststand in dem Augenblick, in dem der Abstand zwischen Kesselvorlauf und
Speicher auf 2 K gefallen war. Mit der vorherigen Schwelle von 0,5 K lief die Pumpe nach dem
Brennerende noch rund fünf Stunden weiter. Während eines Brennerlaufs gilt die Schwelle nicht:
Am 23. September startete das Gerät am Kessel mitten in einem Lauf neu, die Pumpe blieb bei
0,9 bis 2,5 K Abstand stehen, und der Kessel schaltete den Brenner nach gut zwölf Minuten selbst
ab. Seitdem läuft die Pumpe, solange der Brenner läuft, und ein Neustart beginnt bei laufender
Pumpe.

**Füllstand und Warmwasser.** Das Gerät am Kessel hat den Nullpunkt des Füllstands am
5. September zum ersten Mal an einem Brennerstart nachgemessen, von 51,5 auf 51,8 °C; das Gerät
am Speicher hat diesen Brennerstart nicht erfasst. Ein Vollbad ließ den Speicher in einer
halben Stunde um 6,5 K fallen, im Stillstand verliert er 0,8 K je Stunde. Die Zapfschwelle von
2 K in 15 Minuten liegt zwischen beiden.

**Rückströmung.** Bei stehender Pumpe und ausgeschaltetem Brenner stieg der Kesselrücklauf
während einer Warmwasserzapfung von 36,9 auf 46,3 °C, während der Vorlauf bei 32 °C blieb:
Heißes Wasser strömt aus dem Speicher in die Rücklaufleitung des Kessels. Am Stichtag meldete
das Gerät am Kessel zwei solche Ereignisse innerhalb von elf Stunden, mit bis zu 10,1 K
Anstieg. Die Ursache liegt in der Verrohrung, vermutlich an einer fehlenden oder undichten
Schwerkraftbremse.

**Bedarfskette.** Alle drei Verteiler meldeten dauerhaft Wärmebedarf, ohne dass
ein Raum etwas abgerufen hätte: zwölf Kreise standen auf Anschlag offen, weil
sie keinem Raum zugeordnet sind und unbekannte Stellungen beim ersten Start
einmal angefahren werden. Bedarf meldet jetzt nur, was geregelt wird; solche
Kreise werden zudem zugefahren. Nachgewiesen: `demand: false` auf allen drei
Verteilern, alle zwölf Kreise in zwei Minuten auf 0 — paarweise, weil in einer
Messgruppe immer nur ein Kanal fahren darf.

**Sicherung der Einstellungen.** Rundlauf über die vier damals laufenden Geräte geprüft: Räume,
Fühlerrollen, Fahrzeiten, Auslöseschwellen und Relaisangaben kommen vollständig
zurück, der Netzzugang bleibt unverändert, und eine Sicherung des jeweils
anderen Gerätetyps wird abgewiesen.

Vermessen sind 16 der 33 Kreise: drei im Keller, sechs im Erdgeschoss und sieben im
Obergeschoss. Bis auf zwei Kreise im Obergeschoss liegen die Messfahrten unter den
Vorgabewerten; Obergeschoss 8 fährt deutlich langsamer und löst erst bei 210 mV aus. Eine
Auswahl:

| Kreis | auf | zu | Auslöseschwelle |
|---|---|---|---|
| Keller 1 | 36,1 s | 38,1 s | 166 mV |
| Keller 2 | 38,4 s | 39,5 s | 168 mV |
| Keller 4 | 33,7 s | 35,2 s | 182 mV |
| Erdgeschoss 1 | 33,9 s | 34,9 s | 163 mV |
| Obergeschoss 5 | 34,2 s | 35,6 s | 191 mV |
| Obergeschoss 8 | 42,2 s | 45,3 s | 210 mV |
| Vorgabe | 39 s | 40 s | 190 mV |

Nicht erprobt sind Anzeige (SSD1327) und DS18B20 an der Verteilerplatine, weil beide dort
nicht dauerhaft angeschlossen sind, und die Raumregelung unter Heizlast: Seit Beginn der
Aufzeichnung wurde fast nur Warmwasser bereitet. Ein Broker ist bislang nicht eingerichtet,
die MQTT-Anbindung deshalb ebenfalls unerprobt.

Beide Auswertungen rechnen inzwischen. Die Verbrauchslinie stützt sich auf 28 Tage, erklärt die
Laufzeit aber noch nicht: Im Spätsommer hängt sie fast nur am Warmwasser, das Bestimmtheitsmaß
liegt bei 0,006. Aussagekraft erhält sie erst in der Heizperiode. Der Abgas-Vorlauf-Abstand
liegt aus 23 Ladungen bei 7 K, unverändert gegenüber dem Stand nach der Reinigung am
17. August.

## Offene Punkte

- **Tastenschwellen** (1000, 870, 1000) sind nur ein Ausgangspunkt: Sie hängen
  an der Messdauer der Treiberfassung und sind unter **Sensoren**
  nachzustellen.
- **MAC-Adressen der Thermometer** ergeben sich beim ersten BLE-Empfang.
- **Düsendurchsatz** (2,2 l/h) ist angenommen, nicht gemessen. Die Verbrauchsschätzung und
  jede daraus abgeleitete Größe hängen an diesem Wert; maßgeblich ist die Angabe auf der Düse
  oder im Wartungsprotokoll.
- **Matter und Thread** sind nicht umgesetzt. Thread scheidet auf dieser
  Platine aus, weil dem ESP32-WROOM-32 das 802.15.4-Funkteil fehlt. Matter über
  WLAN passt nicht in den verfügbaren Programmspeicher. Wird Matter gebraucht,
  reicht Home Assistant die vorhandenen MQTT-Entitäten über seine eigene
  Matter-Bridge weiter.

## Geplante Erweiterungen

Die Auswertung der Protokolle ist in Stufen angelegt; umgesetzt sind die
Datengrundlage, die Plausibilitätsprüfungen der Fühler, die Verbrauchslinie, der
Abgas-Vorlauf-Abstand, die Erkennung der Rückströmung und die Zählung der
Warmwasserzapfungen. Offen sind:

- **Stillstandsverlust des Speichers.** Aus dem Abkühlen ohne Brennerlauf und
  ohne laufende Pumpe ergibt sich die Zeitkonstante der Dämmung. Ändert sie
  sich, deutet das auf ein Rückschlagventil, das nicht schließt.
- **Fahrzeit der Antriebe.** Die wöchentliche Schutzfahrt fährt ohnehin jeden
  Kreis auf Anschlag und könnte dabei die Fahrzeit messen. Wächst sie über
  Monate, sitzt das Ventil schwerer.
- **Auswertung auf dem Rechner.** Ein Werkzeug unter `tools/`, das die CSV-Dateien
  aller Geräte einliest. Es setzt einen Winter Daten voraus.

Die zugehörigen Konzepte:

- [Konzept: Auswertung der Anlage mit statistischen Verfahren](docs/konzept-auswertung.md)
  — Datengrundlage, Verfahren auf dem Gerät, Auswertung außerhalb, und was
  bewusst nicht vorgesehen ist
- [Konzept: Wärmeerzeugung, Pufferspeicher und Pumpensteuerung](docs/konzept-waermeerzeuger.md)
  — Messstellen, Brennererkennung, Ladezustand, Bedarfserkennung, Pumpenlogik, Schnittstellen
- [Umbau auf zwei Anwendungen](docs/umbau-projektstruktur.md)
  — Aufteilung des Projekts, gemeinsame Komponenten, Nachweis der Unverändertheit

## Fremdkomponenten

Grundlage der Firmware ist das ESP-IDF von Espressif; der Empfang der
Raumthermometer setzt auf NimBLE auf. Über die ESP-IDF-Registry werden zur
Bauzeit vier Komponenten eingebunden, die eigenen Lizenzen unterliegen und
nicht Teil dieses Quelltextbestands sind:

| Komponente | Lizenz |
|---|---|
| `espressif/cjson` | MIT |
| `espressif/mqtt` | Apache-2.0 |
| `espressif/onewire_bus` | Apache-2.0 |
| `espressif/ds18b20` | Apache-2.0 |

Die Raumthermometer senden mit der freien Fremdfirmware ATC beziehungsweise
pvvx. Das Gehäuse ist mit CadQuery konstruiert.

## Lizenz

| Teil | Lizenz |
|---|---|
| Firmware, Werkzeuge, Dokumentation, `case/` | GNU General Public License, Version 3 — [LICENSE](LICENSE) |
| Entwurfsdaten der Platine, `board/` | CERN Open Hardware Licence v2, Strongly Reciprocal — [board/LICENSE](board/LICENSE) |

Die GPL folgt der Vorlage, auf die dieses Projekt zurückgeht — siehe
[Herkunft](#herkunft). Für die Platine passt sie nicht: Ihre Rückgabepflicht
hängt am Weitergeben von Objektcode, und eine gefertigte Leiterplatte ist keine
Kopie der Entwurfszeichnung. Die CERN-OHL knüpft dieselbe Pflicht an das
Bereitstellen des Produkts. Die Haltung ist in beiden Fällen dieselbe: offen,
mit Rückgabe. Einzelheiten in [board/README.md](board/README.md).

Das Gehäuse unter `case/` ist ein CadQuery-Programm und bleibt deshalb bei der
GPL.

Die eingebundenen Fremdkomponenten stehen unter MIT und Apache-2.0. Beide
lassen sich mit der GPL-3.0 zusammenführen; die zusammengesetzte Firmware
unterliegt dann der GPL-3.0.

Die Software wird ohne jede Gewährleistung bereitgestellt. Sie steuert eine
Heizungsanlage: Wenn Sie sie einsetzen, tun Sie das auf eigenes Risiko. Gehen
Sie die [Prüfungen](#prüfungen) an der eigenen Hardware durch, bevor Sie die
Anlage unbeaufsichtigt laufen lassen.

## Marken

HmIP und Homematic IP sind Marken der eQ-3 AG. Sie werden hier ausschließlich
genannt, um die verbauten Stellantriebe zu bezeichnen. Es besteht keine
Verbindung zu eQ-3, und es wird weder eine Kompatibilität noch eine Freigabe
behauptet.

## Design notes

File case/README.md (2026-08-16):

# Gehäuse

Zweiteiliges Druckgehäuse für die Steuerplatine: Unterschale und Deckel, dazu
Displayaufnahme, Wandlaschen und ein optionaler Hutschienen-Clip. Den Deckel
gibt es in zwei Varianten, mit und ohne Displayausschnitt; beide passen auf
dieselbe Unterschale. Konstruiert
mit CadQuery; Quelle der Wahrheit ist [`fbh_case.py`](fbh_case.py). STEP, STL
und 3MF sind erzeugt und werden nie von Hand geändert.

Der Aufbau folgt der Vorgehensweise aus einem anderen Projekt
(`smartCamper/hardware/case`); die Werkzeuge in [`tools/`](tools/) sind von
dort übernommen. Abweichungen sind in `tools/make_3mf.py` im Kopf vermerkt.

| Maß | Wert |
|---|---|
| Platine | 150,0 × 92,0 mm, Eckradius 3,0 mm |
| Gehäusekörper | 155,0 × 97,0 mm |
| Außenmaß mit Ohren und Laschen | 184,0 × 102,9 × 31,2 mm |
| Wand / Boden / Deckel | 2,0 / 2,0 / 3,0 mm |
| Lichte Höhe über der Platine | 21,0 mm |
| Werkstoff | PETG (siehe **Sicherheit**) |

## ⚠️ Sicherheit

Auf der Platine liegt **Netzspannung**: ein HLK-5M03 und die Klemme `220`. Die
gefrästen Trennschlitze der Platine grenzen den Netzbereich auf X ≥ 113,8 und
Y ≥ 64,2 ein. Das Gehäuse hält diesen Bereich frei — dort gibt es keine
Lüftungsschlitze, keine Displayaufnahme und keine Bohrung außer der
Kabelverschraubung. Der Skriptlauf [`sonden.py`](sonden.py) prüft das.

Zwei Punkte bleiben in Ihrer Verantwortung:

- **PETG ist nicht flammwidrig** (UL94 HB). Für ein dauerhaft netzgespeistes
  Gerät ist ein Werkstoff der Klasse V-1 oder V-0 vorzuziehen — PETG-FR,
  PC-FR oder ABS-FR. Auf einem offenen Drucker fällt ABS aus; wer beim
  offenen Drucker bleibt, sollte das Gerät nicht unbeaufsichtigt betreiben
  oder die Baugruppe zusätzlich in einen zugelassenen Installationskasten
  setzen.
- **Die Zugentlastung der Netzzuleitung ist keine Option.** Vorgesehen ist
  eine Kabelverschraubung M12 × 1,5 in der Nordwand (Bohrung Ø 12,2 bei
  X = 137). Eine blanke Bohrung genügt nicht.

Die Klemme `220` hat 3,5 mm Rastermaß. Ob das für die vorgesehene
Anschlussart ausreicht, ist eine Frage an die Platine, nicht an das Gehäuse.

## Erzeugen

```bash
cd case && .venv/bin/python fbh_case.py
```

Die Umgebung ist eine geteilte venv (`cadquery`, `ezdxf`, `Pillow`); der
Symlink `.venv` zeigt auf die des Nachbarprojekts. Neu anlegen:

```bash
python3.12 -m venv .venv && .venv/bin/pip install cadquery ezdxf shapely Pillow
```

Prüfen — beides gehört dazu:

```bash
MODUL=fbh_case .venv/bin/python tools/check_case.py
```

```bash
.venv/bin/python sonden.py
```

`check_case.py` findet ungültige Körper, undichte Netze und Kollisionen.
`sonden.py` findet, was dabei durchfällt: **verschlossene Löcher** (eine
Kollision ist es nicht — es ist Material an der falschen Stelle), die
Freiräume von Displaymodul und Halterahmen und die Vollständigkeit der
Netzbereichs-Abschottung. Beim ersten Bau hat genau das zwei Fehler gefunden,
die alle anderen Prüfungen passiert hatten (siehe **Gefundene Fehler**).

## Druckdateien

Drei Platten, drei Dateien — sie passen nicht gemeinsam auf 256 × 256 mm:

```bash
.venv/bin/python tools/make_3mf.py fussbodenheizung-gehaeuse.3mf
```

```bash
DISPLAY_MODUL=0 .venv/bin/python tools/make_3mf.py fussbodenheizung-gehaeuse-ohne-display.3mf
```

```bash
PLATTE=zubehoer .venv/bin/python tools/make_3mf.py fussbodenheizung-zubehoer.3mf
```

```bash
PLATTE=proben .venv/bin/python tools/make_3mf.py fussbodenheizung-pruefstuecke.3mf
```

| Datei | Inhalt | Belegt |
|---|---|---|
| `fussbodenheizung-gehaeuse.3mf` | Deckel (3 Teile: Korpus, Logo-Ring, Logo-Akzent) und Unterschale | 184 × 214 mm |
| `fussbodenheizung-gehaeuse-ohne-display.3mf` | dasselbe mit geschlossenem Deckel | 184 × 214 mm |
| `fussbodenheizung-schale-schnapper.3mf` | nur die Unterschale, Schnapp-Dome | 184 × 103 mm |
| `fussbodenheizung-schale-randclips.3mf` | nur die Unterschale, Federzungen | 184 × 103 mm |
| `fussbodenheizung-zubehoer.3mf` | Displayrahmen, 2 × Hutschienen-Clip | 154 × 50 mm |
| `fussbodenheizung-pruefstuecke.3mf` | Prüfstück Südwand, Prüfstück Display | 232 × 58 mm |

Der Deckel ist **ein** Objekt mit drei Teilen; in Bambu Studio lässt sich je
Teil ein Filament wählen. Er steht mit der Oberseite auf der Platte — die
Logotaschen sind damit die ersten Lagen. **Sie müssen gefüllt werden**: bliebe
eine leer, müsste die Lage darüber über Luft brücken.

## ⚠️ Zuerst die Prüfstücke drucken

In den Fertigungsdaten der Platine steht **keine einzige Bauhöhe** — die DXF
zeigt nur den Bestückungsdruck. Am 16.08.2026 sind die vier wichtigsten Höhen
am Board nachgemessen worden und im Skript mit `⭐ GEMESSEN` gekennzeichnet;
`[SCHAETZUNG]` steht noch an der Klemme `220`, den 1×2-Buchsenleisten und
sämtlichen Displaymaßen. Die beiden Prüfstücke kosten zusammen rund eine
Stunde Druckzeit und stehen gegen zwei verworfene Großteile:

- **Prüfstück Südwand** — ein 10 mm tiefer Schnitt durch die fertige Schale mit
  allen elf RJ11-Öffnungen. Prüft, ob die Stecker einrasten und ob die Rastnase
  erreichbar bleibt.
- **Prüfstück Display** — der Displayausschnitt aus dem fertigen Deckel mit
  Sichtfenster, Glastasche und den vier Domen. Prüft Fenstergröße und
  Einbautiefe des Moduls.

Beide sind **aus den fertigen Körpern geschnitten**, nicht nachmodelliert — sie
können deshalb nicht vom Gehäuse abweichen.

Passt etwas nicht, ändert sich kein Quelltext. Die kritischen Maße hängen an
Umgebungsvariablen:

```bash
RJ_OPEN_Z0=2.4 RJ_OPEN_Z1=11.8 DSP_GLASS_D=2.4 .venv/bin/python fbh_case.py
```

| Variable | Vorgabe | Was sie steuert |
|---|---|---|
| `RJ_H` | 14,5 ⭐ | Bauhöhe der RJ11-Buchse |
| `RJ_DEPTH` | 14,0 ⭐ | Bautiefe der RJ11-Buchse |
| `RJ_OPEN_W` | 9,8 | Breite der Stecköffnung |
| `RJ_OPEN_Z0` / `_Z1` | 0,2 / 13,2 ⭐ | Unter- und Oberkante der Öffnung über der Platinenoberkante |
| `DSP_W` / `DSP_H` | 42,0 / 37,5 | Umriss der Displayplatine |
| `DSP_GLASS_W` / `_H` / `_D` | 30,5 / 33,5 / 2,0 | Glasfläche und ihr Überstand |
| `ESP_SOCKET` / `ESP_ABOVE` | 11,16 / 4,7 ⭐ | Buchsenleiste und Aufbau des DevKit (gemessen ist die Summe) |
| `HLK_H` | 18,4 ⭐ | Bauhöhe des Netzteils — bestimmt `TOP_CLEAR` |
| `KF250_H`, `HDR_H` | 10,5 / 8,5 | Klemme, 1×2-Buchsenleisten |
| `TOP_CLEAR` | 21,0 | Lichte Höhe über der Platine |
| `WALL` / `BOTTOM` | 2,0 / 2,0 | Wand- und Bodenstärke |
| `SNAP_D` / `SNAP_SLOT` / `SNAP_BARB_D` | 2,5 / 0,8 / 3,3 | Schnapp-Dom: Schaft, Schlitz, Widerhaken |
| `CLIP_T` / `CLIP_OVER` | 1,0 / 0,6 | Federzunge: Dicke und Übergriff |

⭐ = am Board gemessen. `BOT_CLEAR` liegt fest auf 3,6 mm: die längsten
Lötstellen stehen 3,0 mm unter der Platine vor, darunter bleiben 0,6 mm Luft.

## Aufbau

**Koordinaten.** Ursprung ist die linke untere Platinenecke in der Draufsicht,
`Z = 0` der Gehäuse-Außenboden. Alle XY-Maße kommen aus den Fertigungsdaten in
[`../board/`](../board/) und lassen sich nachvollziehen:

```bash
.venv/bin/python reference/platine_auslesen.py
```

**Südwand.** Elf Stecköffnungen von 9,8 × 13,0 mm auf den Buchsenmitten, dazwischen
3,53 mm Steg. Die Buchsenfront liegt 1,1 mm innerhalb der Platinenkante, der
Stecker überwindet also 3,6 mm Tunnel.

⚠️ Die 13,0 mm lichte Höhe folgen der gemessenen Frontöffnung der Buchse und
sind deutlich mehr, als ein 4P4C-Stecker mit Rastnase braucht (~9,5 mm). Sehr
wahrscheinlich ist die äußere Frontmulde gemessen worden und nicht der
eigentliche Steckerschlitz. Das ist die sichere Richtung — die Buchse begrenzt
selbst, was durchpasst —, kostet aber Material zwischen den elf Löchern. Wird
der Schlitz nachgemessen, gehört `RJ_OPEN_Z1` nach unten.

Die Buchse ist 14,0 mm tief statt der 13,0 aus dem Bestückungsdruck. Wohin der
Millimeter geht, sagt die Tiefe allein nicht — fest liegen nur die Rastzapfen
bei Y = 7,095. Angenommen ist deshalb, dass die Front bei Y = 1,10 bleibt und
der Millimeter nach hinten wächst. Das ist die sichere Richtung: läge die Front
weiter vorn, würde der Steckertunnel nur kürzer. Umgekehrt könnte die Wand
gegen die Buchse drücken.

**Nordwand.** Kabelverschraubung M12 × 1,5 für die Netzzuleitung (X = 137, im
Netzbereich) und Ø 7 für den Vorlauffühler (X = 76) mit zwei Rippen als
Klemmschlitz. Dazu Lüftungsschlitze über dem DevKit.

**Westwand.** Lüftungsschlitze auf Höhe des HDC1080 — er misst das
Schaltschrankklima, ohne Luftaustausch misst er das Gehäuseinnere.

**Deckelbefestigung.** Sechs M3 in **angeformten Außenohren**, nicht in
Innensäulen. Die Platine füllt die Kavität vollständig aus; jede Innensäule
läge in einer RJ11-Buchse, im DevKit oder im Netzteil. Nebeneffekt: die
Zentrierlippe läuft ringsum ununterbrochen. Die Südkante bekommt keine
Schraube — dort steht über die volle Breite die Steckerreihe; sie wird von der
Lippe und den beiden Ohren bei Y = 12 gehalten.

**Platine.** Drei Varianten der Befestigung, über `PCB_HALT` wählbar. Alle
drei haben dieselben Außenmaße und **denselben Deckel** — wer die Wahl später
revidiert, druckt nur die Unterschale neu.

| `PCB_HALT` | Prinzip | Randdehnung | Demontage |
|---|---|---|---|
| `schrauben` (Vorgabe) | 4 × M2,5 selbstschneidend in Dome Ø 6,0 | — | beliebig oft |
| `schnapper` | Schnapp-Dome durch die vorhandenen Ø 2,7-Bohrungen | 1,59 % | Schenkel mit der Pinzette zusammendrücken |
| `randclips` | 4 Federzungen an der Platinenkante | 2,34 % | Zunge mit dem Finger wegdrücken |

```bash
PCB_HALT=schnapper PLATTE=schale .venv/bin/python tools/make_3mf.py fussbodenheizung-schale-schnapper.3mf
```

⚠️⚠️ **Die Federwege sind gerechnet, nicht geraten.** Randdehnung einer
eingespannten Biegefeder: `ε = 3·t·δ / (2·L²)`. PETG verträgt dauerhaft etwa
2 … 3 %; darüber bleibt die Feder verformt oder reißt. Diese Rechnung setzt der
Zungendicke die Grenze — mit 1,4 mm und 0,9 mm Übergriff wären es **4,1 %**,
die Zunge bliebe nach dem ersten Einclipsen offen stehen. Mehr Übergriff
braucht eine **längere** Feder, also `BOT_CLEAR` 6,0 statt 3,6 und damit ein
2,4 mm höheres Gehäuse.

⚠️ Beim Schnapp-Dom entscheidet der **Schlitz** über die Federlänge: er reicht
bis 0,8 mm über den Boden hinunter, tief in den Dom hinein. Endete er an der
Platinenunterkante, wäre die Feder nur 2,1 mm lang und die Randdehnung spränge
auf über 8 %.

⚠️ Die Ausweichtaschen der Randclips liegen **in der Wand**. Ohne die örtliche
Verdickung nach außen hätten sie die Wand durchbrochen — bei einem Netzgerät
ein Loch nach außen. `sonden.py` prüft an allen vier Zungen, dass dahinter
Material steht.

Die Dome selbst sind in allen Varianten gleich: Ø 6,0, 3,6 mm hoch, also
unkritisch schlank. Bei `schrauben` sitzt darin das Ø 2,05-Kernloch (1,98 mm
Domwand).

**Stützung unter der Buchsenreihe.** Die vier Befestigungsbohrungen der Platine
liegen alle in der oberen Hälfte (Y 46,9 … 87,5) — unter der RJ11-Reihe stützte
nichts, und dort wird elfmal ein Stecker hineingedrückt. Dazu kommen in allen
drei Varianten:

- **11 Pads Ø 6,0 auf Y = 3,0**, je eines auf einer Buchsenmitte — genau dort,
  wo der Stecker drückt
- eine **durchgehende Querrippe bei Y 15,0 … 18,0**

Die freie Platinenlänge zwischen Südkante und erster Abstützung sinkt damit von
46,9 auf **28,9 mm**.

⭐ **Wo gestützt werden darf, ist gerechnet, nicht ausgesucht.** Die Unterseite
ist an der Südkante dicht belegt: bei Y ≈ 4 … 7 die Buchsenpins und Rastzapfen,
bei Y ≈ 0,6 … 5,6 die Buchsenleisten. Eine Suche über alle 286 Bohrungen aus
den PTH- und NPTH-Daten liefert zwei freie Bänder — die elf Flecken auf den
Buchsenmitten (5,14 mm bis zur nächsten Lötstelle) und das Band bei Y 15 … 18
(2,22 mm). Dass die freien Flecken mittig unter den Buchsen liegen, ist kein
Zufall: die Pins stehen links und rechts davon.

Die X-Werte der Pads kommen deshalb aus `RJ_X` und nicht aus einer zweiten
Liste. `sonden.py` liest die Bohrdaten bei jedem Lauf neu ein und prüft den
Abstand — ein Pad auf einer Lötstelle hebt die Platine an, und keine der
anderen Prüfungen sieht das: der Platinen-Dummy hat keine Lötstellen, also gibt
es auch keine Kollision.

**Wandstärke.** 2,0 mm für Wand und Boden, 3,0 mm für den Deckel. Die 2,0
sind nicht nur Material: der Steckertunnel vor den RJ11-Buchsen ist
`WALL + CLR + 1,10` und schrumpft damit von 4,0 auf 3,6 mm — je kürzer er ist,
desto sicherer liegt die Rastnase des Steckers außerhalb und lässt sich
drücken.

Dünner geht, aber nicht beliebig. Drei Grenzen:

- Das **Außenohr** überlappt die Wand um `WALL − 0,4`. Unter etwa 0,9 mm wird
  daraus eine Berührung, und tangentiale Berührung heißt kaputtes Netz — genau
  das hatten die ursprünglich runden Ohren. Ein Riegel im Skript bricht ab,
  bevor es so weit kommt.
- Die **Südwand** ist zwischen den elf Öffnungen nur 3,53 mm breit. Sie trägt
  als Leiter mit zwei durchgehenden Holmen, aber dünn wird sie weich.
- Die **Kabelverschraubung M12** will 1 … 4 mm Wand; unter 1,5 sitzt die Mutter
  nicht mehr sauber.

Was die Wand kostet (Unterschale, gemessen):

| `WALL` | Volumen | Tunnel | Ohr-Überlappung |
|---|---|---|---|
| 2,4 | 72,3 cm³ | 4,0 mm | 2,0 mm |
| **2,0** | **61,7 cm³** | **3,6 mm** | **1,6 mm** |
| 1,8 | 56,5 cm³ | 3,4 mm | 1,4 mm |
| 1,6 | 51,3 cm³ | 3,2 mm | 1,2 mm |

```bash
WALL=1.8 BOTTOM=1.8 .venv/bin/python fbh_case.py
```

Wer auf ganze Bahnen kommen will: mit 0,4-mm-Düse und 0,42 Bahnbreite sind
1,68 (4 Bahnen) und 2,10 (5 Bahnen) die sauberen Werte. 2,0 slict Bambu Studio
als fünf leicht schmalere Bahnen — unkritisch, aber nicht exakt.

⚠️ **`LID_T` bleibt bei 3,0 und ist nicht verhandelbar.** Über der 2,0 mm
tiefen Glastasche des Displays blieben sonst weniger als 1,0 mm stehen. Das ist
die engste Stelle des Deckels, nicht die Kantenrundung.

**Wandmontage.** Vier Laschen mit Ø 4,5 an den seitlichen Ohren.
Lochabstand 174,0 × 68,0 mm.

**Hutschiene.** Zwei Clips, je einer unter die Laschen bei Y = 80 geschraubt
(M4-Senkschraube, Kopf bleibt bündig — dort liegt die Schiene auf). Sie
greifen dieselbe waagerechte TS35-Schiene; das Paar verhindert das Verdrehen,
das eine einzelne Schraube zuließe.

**Display.** Das Modul wird von einem Halterahmen gegen die Deckelunterseite
geklemmt, **nicht** über sein Bohrbild gehalten. Damit zählt nur der Umriss —
und der ist mit einem Messschieber in zehn Sekunden nachgemessen, während ein
Bohrbild geraten wäre.

**Deckel ohne Display.** `DISPLAY_MODUL=0` lässt Sichtfenster, Glastasche und
die vier Dome weg; Halterahmen und Displayprüfstück entfallen mit. Umriss,
Lippe, Schrauben, Tastenfelder, Logo und Bauhöhe bleiben gleich — die beiden
Deckel sind gegeneinander austauschbar. Die Bauhöhe sinkt dabei **nicht**:
`TOP_CLEAR` folgt dem Netzteil (18,4 mm), nicht dem Display. Der geschlossene
Deckel wiegt 45,3 statt 42,6 cm³.

⚠️ Die Umgebungsvariable heißt bewusst `DISPLAY_MODUL` und nicht `DISPLAY` —
letztere ist unter X11 belegt und hätte die Variante je nach Umgebung von
selbst umgeschaltet.

**Schraubensitze.** 90°-**Senkungen**, keine zylindrischen Senkbohrungen, also
Senkkopfschrauben M2,5 (DIN 7991 / ISO 10642). Das Kernloch im Ohr ist
**20,0 mm tief** (`EAR_PILOT_H`) und lässt damit Schrauben bis M2,5 × 20 zu;
darunter bleiben noch 8,2 mm massives Ohr stehen, die Wandlasche wird nicht
angeschnitten.

⚠️ Mehr Einschraubtiefe ist nicht automatisch mehr Halt. Eine selbstschneidende
M2,5 × 20 muss über 17 mm Gewinde **formen** — das Drehmoment summiert sich, und
irgendwann reißt eher der Kopf ab oder das Ohr spaltet, als dass die Schraube
hält. Wer die Länge nutzt, sollte langsam und ohne Schlagschrauber eindrehen
oder gleich Kunststoffschrauben mit Flachgewinde nehmen. Für häufiges Öffnen
wäre eine durchgehende Bohrung mit Mutter unter dem Ohr die haltbarere Lösung
als ein langes Kernloch.

Dass es eine Senkung sein muss und keine zylindrische Senkbohrung, ist keine
Optik: der Deckel wird mit der Oberseite aufs Bett gedruckt, eine Ø6,2-Tasche von 1,8 mm läge
also in den ersten Lagen und schlösse sich erst dort über einem Ø3,3-Loch —
sechsmal ein freitragender Ring von 1,45 mm, und genau das war die **einzige**
Stützstelle des Deckels. Der 90°-Kegel läuft mit 45° aus dem Bett heraus und
trägt sich selbst. Beide Deckelvarianten haben damit **null** nach unten
zeigende Flächen.

**Tasten.** Drei Membranfelder Ø 18 mit 1,0 mm Restwand, von innen ausgespart.
Die Sensorfläche (Kupferscheibe Ø 17,5 oder Alu-Klebeband) wird in die Mulde
gelegt und verklebt; die Leitungen gehen an GPIO 4, 2 und 15 der
Buchsenleiste. Die Deckeloberseite bleibt glatt — beschriftet wird graviert.

## Gravur

```bash
.venv/bin/python laser_gravur.py
```

`gravur_deckel.png` ist die Datei für den LaserPecker 4 (600 dpi, schwarz auf
weiß, Bildbreite **166,8 mm** — das ist die Deckelbreite über die Ohren).
`gravur_deckel_lage.png` zeigt zusätzlich Umriss, Sichtfenster, Tastenfelder,
Logotasche und Schraubensenkungen als graue Hilfslinien; sie dient nur der
Lagekontrolle und gehört nicht in die Maschine.

⚠️ **Mit 1064 nm markiert PETG nicht** — der Faserlaser braucht Ruß als
Absorber und findet ihn nur in schwarzem Material. Für Kunststoff ist der
450-nm-Teil des LP4 der richtige.

Kanalnummern, Tastenmitten und Fensterlage werden nicht doppelt gepflegt: das
Skript importiert `fbh_case` und leitet alles aus denselben Werten ab. Ändert
sich ein Buchsenabstand, wandert die Ziffer mit.

## Gefundene Fehler

Zwei Befunde aus dem Bau, damit sie nicht wiederkehren:

**⚠️⚠️ Zwei Bohrungen wurden ins Freie geschnitten.** Die Ebene `"XZ"` hat in
CadQuery die Normale (0, −1, 0): `extrude(+L)` läuft nach **Süden**.
1-Wire-Durchführung und Netzverschraubung standen mit negativer Länge da und
lagen damit außerhalb des Gehäuses. Der Körper blieb gültig, das Netz dicht,
die Kavität kollisionsfrei — `check_case.py` meldete nichts. Gefunden hat es
erst die Sondenlinie. Und die Sonde hat den Dreher zunächst mitgemacht: sie
maß Luft außerhalb des Gehäuses und meldete „offen".

**⚠️⚠️ Runde Außenohren ergaben ein kaputtes STL.** Ein runder Zapfen, dessen
Mitte außerhalb der Wandflucht liegt, schneidet die gerade Wand in sehr
flachem Winkel. Der 1,5-mm-Kantenradius des Deckels lief dort in eine fast
entartete Ecke: 24 offene Kanten im tesselierten Netz an genau diesen zwölf
Stellen. Rechteckige Ohren treffen die Wand mit zwei sauberen 90°-Ecken; auch
deren Außenecken bleiben scharf, weil eine XY-Verrundung die Seitenflächen als
Bogen bis in die Wandflucht zöge und das Problem abgeschwächt zurückbrächte.

**⚠️⚠️ Zwei Displaydome standen im Displaymodul.** Ihre Unterseite liegt in der
Ebene der Modulrückseite — dort halten sie den Halterahmen —, jede Überlappung
in XY ist also ein Dom im Modul. Zwei ragten 1,0 mm hinein. `check_case.py`
prüft Deckel gegen Platine und Schale, nicht gegen das Modul: das ist kein
Druckteil und kommt in keinem der Körper vor. Gemeldet hat es erst die
Prüfung *Modulplatine gegen Deckel* in `sonden.py`, die es vorher nicht gab.
Beim Verschieben nach außen lief dann der Halterahmen ins Netzteil — die
Displaygruppe sitzt jetzt 2,25 mm weiter südlich.

**⚠️ Eine Prüfung meldete einen Konflikt, den es nicht gab.** Der erste Versuch
verglich Displaydom und Buchsenreihe rein in XY und meldete „−1,10 mm zu eng".
Die Dome reichen aber nur bis zur Modulrückseite herunter und nie auf
Buchsenhöhe. Ersetzt durch den senkrechten Abstand unter dem Halterahmen —
dem einzigen Displayteil, das wirklich tief kommt.

**⚠️ Sechs Schraubensitze und zwei Rippen brauchten Stützmaterial.** Die
zylindrischen Senkbohrungen im Deckel schwebten 1,8 mm über dem Bett, und die
beiden Zugentlastungsrippen der 1-Wire-Durchführung endeten 4,5 mm frei in der
Luft. Beides meldet keine der Prüfungen — ein Überhang ist weder eine
Kollision noch ein verschlossenes Loch. Gefunden über eine Auswertung der nach
unten zeigenden Flächen beider Teile in Druckstellung; die Senkbohrungen sind
jetzt 90°-Senkungen, die Rippen laufen mit 45° aus der Wand.

**⚠️ Der Federarm des Hutschienen-Clips hing in der Luft.** Der Schlitz, der
ihn federn lassen sollte, hat ihn abgetrennt — zwei Körper, beide gültig.
`check_case.py` sieht Zubehörteile nicht; gemeldet hat es erst Bambu Studio mit
`number_of_parts = 2`. Jetzt federt eine Zunge, die an ihrer Wurzel
durchgehend an der Platte hängt, und `sonden.py` prüft alle Zubehörteile auf
einen Körper und ein dichtes Netz.

## Offene Punkte

- Die Höhenlage der RJ11-Stecköffnung ist gemessen, aber vermutlich an der
  Frontmulde statt am Steckerschlitz — siehe **Südwand**.
- Die 18,4 mm des HLK-5M03 liegen 3,4 mm über dem Datenblattmaß (15,0). Das
  Modul sitzt also nicht bis zum Anschlag durchgesteckt. Gebaut ist nach dem
  gemessenen Wert; wird das Modul nachgesetzt, ist das Gehäuse zu hoch, nie zu
  niedrig.
- Klemme `220` und 1×2-Buchsenleisten sind weiterhin geschätzt.
- Die Maße des Displaymoduls sind die des Waveshare 1,5″ OLED aus der
  Katalogangabe, nicht aus einem Datenblatt. Glasfläche und Glasüberstand
  (`DSP_GLASS_*`) sind reine Annahmen.
- Der Hutschienen-Clip ist das einzige Teil, dessen Funktion sich nicht
  rechnerisch belegen lässt — ob die Zunge mit der gewählten Stärke sinnvoll
  federt, zeigt erst der Druck.
- Die Micro-USB-Buchse des DevKit liegt bei X ≈ 59, also 91 mm von jeder
  Außenkante entfernt. Sie ist bewusst nicht herausgeführt; Aktualisierungen
  laufen über OTA. Zum Flashen muss der Deckel ab.

## Dateien

| Datei | Inhalt |
|---|---|
| `fbh_case.py` | Konstruktion — Quelle der Wahrheit (`DISPLAY_MODUL=0`, `PCB_HALT=…`) |
| `sonden.py` | Sondenprüfung (Öffnungen, Freiräume, Netzbereich, Zubehör) |
| `laser_gravur.py` | Gravurvorlage aus der Gehäusegeometrie |
| `reference/platine_auslesen.py` | Platinengeometrie aus Gerber und EasyEDA-JSON |
| `reference/platine.txt` | Ergebnis des Auslesens |
| `tools/` | Übernommen aus `smartCamper/hardware/case/tools` |

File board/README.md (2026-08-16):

# Steuerplatine

Fertigungsdaten der Steuerplatine: Gerber, Bohrdaten, Umriss als DXF, der
EasyEDA-Entwurf und die Stückliste.

| Datei | Inhalt |
|---|---|
| `Gerber_*.zip` | Fertigungsdaten für den Leiterplattenhersteller |
| `PCB_PCB_*.json` | EasyEDA-Entwurf, die bearbeitbare Fassung |
| `PCB_*.dxf` | Umriss, für die Konstruktion des Gehäuses |
| `BOM_*.csv` | Stückliste mit LCSC-Bestellnummern |

Die Platine ist 382 × 234 mm groß und trägt 96 Bauteile in 16 Positionen. Sie
ist in EasyEDA entworfen und von Hand geroutet.

## Lizenz

Copyright 2026 Ruben Mühlhans

Diese Entwurfsdaten beschreiben offene Hardware und stehen unter der
CERN Open Hardware Licence Version 2 – Strongly Reciprocal (CERN-OHL-S v2).
Der Lizenztext steht in [LICENSE](LICENSE).

Sie dürfen diese Daten weitergeben und bearbeiten und Produkte daraus
herstellen, sofern Sie die Bedingungen der CERN-OHL-S v2 einhalten
(<https://ohwr.org/cern_ohl_s_v2.txt>). Wer ein daraus gefertigtes Produkt
weitergibt, muss die zugehörigen Entwurfsdaten zugänglich machen.

Die Weitergabe erfolgt OHNE JEDE AUSDRÜCKLICHE ODER STILLSCHWEIGENDE
GEWÄHRLEISTUNG, insbesondere ohne Gewährleistung der Marktgängigkeit,
zufriedenstellenden Qualität oder Eignung für einen bestimmten Zweck. Es
gelten die Bedingungen der CERN-OHL-S v2.

Bezugsquelle (Source Location): <https://github.com/rubenmuehlhans/floor-heating-ctrl>

Warum nicht die GPL wie die Firmware: Die GPL knüpft ihre Rückgabepflicht an
das Weitergeben von Objektcode. Eine gefertigte Leiterplatte ist aber keine
Kopie der Entwurfszeichnung — die Pflicht liefe ins Leere. Die CERN-OHL knüpft
sie an das Bereitstellen des Produkts und deckt damit auch Rechte ab, die über
das Urheberrecht hinausgehen.

## Herkunft

Das Layout ist eigenständig entstanden. Der Grundgedanke der Schaltung — ein
gesteckter ESP32-Devkit, Kanalauswahl über Schieberegister, Endlagenerkennung
über die Gegenspannung — geht auf das Shield
[esp32_8ch_motor_shield](https://github.com/nliaudat/esp32_8ch_motor_shield)
von nliaudat zurück (CC BY-NC-SA 4.0). Dessen Entwurfsdaten liegen bei OSHWLab
und sind nicht in diesen Bestand eingeflossen.

Unterschiede zum Vorbild: elf statt acht Kanäle, Netzteil auf der Platine statt
Versorgung über USB-C, Anzeige und Schaltschrankfühler mit an Bord.

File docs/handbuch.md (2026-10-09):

# Benutzerhandbuch

Diese Anleitung beschreibt Bedienung, Einrichtung und Wartung der Anlage aus Sicht der
Benutzung. Wie die Firmware aufgebaut ist und warum, steht in den Konzepten:
[Wärmeerzeugung und Pumpensteuerung](konzept-waermeerzeuger.md) sowie
[Umbau auf zwei Anwendungen](umbau-projektstruktur.md).

## Inhalt

- [Was die Anlage tut](#was-die-anlage-tut)
- [Die Geräte](#die-geräte)
- [Erste Inbetriebnahme](#erste-inbetriebnahme)
- [Die Oberfläche](#die-oberfläche)
- [Täglicher Betrieb](#täglicher-betrieb)
- [Räume einrichten](#räume-einrichten)
- [Heizkreise und Messfahrt](#heizkreise-und-messfahrt)
- [Fühler des Heizungsgeräts zuordnen](#fühler-des-heizungsgeräts-zuordnen)
- [Pumpen einrichten](#pumpen-einrichten)
- [Brenner und Pufferspeicher](#brenner-und-pufferspeicher)
- [Außenfühler](#außenfühler)
- [Einstellungen im Einzelnen](#einstellungen-im-einzelnen)
- [Kesselkreispumpe](#kesselkreispumpe)
- [Auswertung](#auswertung)
- [Schutzfahrt und Schutzlauf](#schutzfahrt-und-schutzlauf)
- [Verlauf und Aufzeichnung](#verlauf-und-aufzeichnung)
- [Leitstand](#leitstand)
- [Home Assistant](#home-assistant)
- [Wartung](#wartung)
- [Fehlersuche](#fehlersuche)
- [Anhang](#anhang)

---

## Was die Anlage tut

Ein Ölkessel lädt einen Pufferspeicher. Aus dem Speicher werden zwei Heizkreise versorgt, jeder
über einen Mischer, der den Vorlauf auf die für die Fußbodenheizung nötige Temperatur
herunterregelt. Das Trinkwasser wird im Durchlauf aus dem Pufferinhalt erwärmt.

An jedem Heizkreisverteiler sitzt eine Steuerplatine, die die Ventilstellungen der einzelnen
Kreise regelt. Im Heizungsbereich stehen zwei weitere Geräte: eines am Kessel, eines am
Pufferspeicher. Sie erfassen die Temperaturen und schalten die Umwälzpumpen ab, solange kein
Ventil offen ist.

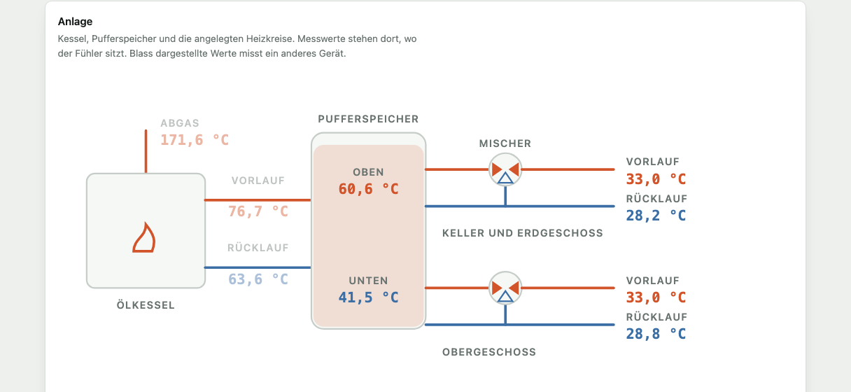
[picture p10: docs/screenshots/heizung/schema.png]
Anlagenschema


Der Kessel selbst wird **nicht** gesteuert, die Mischer ebenso wenig. Deren Regelungen bleiben
unangetastet. Die Firmware misst mit und schaltet ausschließlich die beiden Umwälzpumpen.

## Die Geräte

| Gerät | Aufgabe | Oberfläche |
|---|---|---|
| Verteilerplatine (je Etage eine) | Ventile fahren, Räume regeln | Übersicht, Räume, Kreise, Sensoren, System |
| Gerät am Kessel | Abgas sowie Vor- und Rücklauf messen, Brennerlauf erkennen | Übersicht, Fühler, Verlauf, System |
| Gerät am Pufferspeicher | Speicher und Heizkreise messen, Pumpen schalten | zusätzlich Heizkreise |
| Leitstand (M5Stack Core), wahlweise | Anlage anzeigen, Funkthermometer empfangen, Außentemperatur liefern; regelt nichts | Übersicht, Funk, Einstellungen, System |

Alle Geräte melden sich im Netz gegenseitig an und erscheinen in der Kopfzeile als Verweise. Ein
Klick öffnet die Oberfläche des anderen Geräts; bedient wird stets nur das gerade geöffnete.

Welche Aufgabe ein Heizungsgerät übernimmt, ergibt sich allein aus den zugeordneten Fühlern.
Beide tragen dieselbe Firmware.

## Erste Inbetriebnahme

### Firmware einspielen

Beide Firmwares liegen im selben Quelltextbestand und werden getrennt übersetzt:

```bash
. ~/esp/esp-idf-6.0.2/export.sh
idf.py -C apps/manifold   -p /dev/cu.usbserial-0001 flash    # Verteilerplatine
idf.py -C apps/heatsource -p /dev/cu.usbserial-0001 flash    # Heizungsgerät
```

Spätere Aktualisierungen laufen über die Weboberfläche (**System → Firmware**) oder direkt:

```bash
curl -X POST --data-binary @apps/manifold/build/floor-heating-ctrl.bin http://<adresse>/api/ota
```

Schlägt der Start einer neuen Fassung fehl, kehrt der Bootlader von selbst zur vorherigen
zurück. Bestätigt wird eine Fassung erst, wenn sie vollständig angelaufen ist.

### Ins WLAN bringen

1. Nach dem Einspielen findet das Gerät kein Netz und öffnet einen eigenen Zugangspunkt:
   `floor-heating-XXXX` beziehungsweise `heizung-XXXX`, Kennwort `fussboden`. Die vier Stellen
   sind die letzten beiden Bytes der MAC-Adresse.
2. Verbinden Sie sich damit. Das Einrichtungsfenster öffnet sich von selbst; andernfalls rufen
   Sie `http://192.168.4.1` auf. Der Zugangspunkt ist WPA2-verschlüsselt — manche Rechner
   brauchen zwei, drei Anläufe, bis die Verbindung steht, weil das Netz keinen Weg ins
   Internet hat.
3. **Netze suchen**, Ihr Netz wählen, Kennwort eintragen, speichern.

Einrichtungsportal

Das Gerät verbindet sich und ist danach unter seinem Gerätenamen erreichbar — im Auslieferungs
zustand `floor-heating.local` beziehungsweise `heizung.local`. Stehen mehrere Geräte im Netz,
vergeben Sie unter **System → Netzwerk** unterschiedliche Namen.

### Einrichtungsassistent

Beim ersten Aufruf führt ein Assistent durch die Grundeinrichtung. Er erscheint, solange keine
Bezeichnung eingetragen ist, und lässt sich später über **System** erneut öffnen.

Bei der Verteilerplatine: Aufgabe wählen, Etage benennen, Räume anlegen, je Raum ein Thermometer
wählen. Mit der Aufgabe **Nur Außenfühler** entfallen Räume und Thermometer; stattdessen wird der
Außenfühler gewählt (siehe [Funkbrücke](#funkbrücke-eine-platine-nur-für-den-empfang)).
Beim Heizungsgerät: Gerät benennen, Fühler zuordnen.

## Die Oberfläche

Die Oberfläche liegt im Gerät und lädt ohne Internetzugang. Sie kommt ohne Anmeldung aus und ist
für Telefon und Rechner gleichermaßen gedacht.

Übersicht der Verteilerplatine

Der Verteilerbalken zeigt alle elf Kreise in der Reihenfolge am Verteiler, nach Räumen
gruppiert. Ein **gestrichelter** Kreis gehört zu keinem Raum: er wird nicht geregelt und fährt
nur von Hand. Ein **schraffierter** Kreis hat eine unbekannte Stellung — nach einem Neustart ohne
gespeicherte Stellung, bis er das erste Mal auf Anschlag gefahren ist.

**Kopfzeile.** Links die Bezeichnung des Geräts, daneben die übrigen Geräte im Haus. Darunter
Adresse, Empfangsstärke, Laufzeit, freier Speicher und Version.

**Reiter.** Wechseln die Ansicht. Die Adresszeile führt den Reiter mit (`…/#kreise`), sodass sich
eine Ansicht als Lesezeichen ablegen lässt.

**Farben.** Der Wärmeton steht ausschließlich für heiße Medien und für „läuft" — eine gefüllte
Ventilsäule, ein laufender Brenner, eine laufende Pumpe. Blau steht für Rückläufe, Petrol für
alles Bedienbare.

**Abfragetakt.** Die Oberfläche fragt den Zustand im Sekundentakt ab, solange etwas fährt, sonst
alle sechs Sekunden. Im Hintergrund liegende Fenster fragen nicht ab.

Ansicht auf dem Telefon

## Täglicher Betrieb

### Raum wärmer oder kälter

Auf der **Übersicht** trägt jeder Raum eine Karte mit Ist- und Solltemperatur. Den Sollwert
verstellen Sie über die Schaltflächen **−** und **+** in Schritten von 0,5 K oder durch
unmittelbare Eingabe der Zahl.

Die Ventilstellung folgt der Abweichung proportional: Am Sollwert steht der Kreis halb offen.
Liegt der Raum um das Proportionalband darunter — in der Vorgabe 1 K —, fährt er ganz auf, liegt
er um denselben Betrag darüber, ganz zu. Die Zeile unter den Kreisen nennt die Zielstellung und
wann die Regelung das nächste Mal prüft.

### Raum abschalten

**Ausschalten** fährt die Ventile dieses Raums zu. Für den Bedienenden heißt „aus", dass kein
warmes Wasser mehr durchgeht; ein Messwert wird dafür nicht gebraucht.

Etwas anderes ist ein Raum **ohne gültigen Messwert** — kein Thermometer zugeordnet oder die
Batterie leer. Dort setzt die Regelung aus und lässt die Ventile stehen, wo sie sind: Auf einen
fehlenden Wert zu regeln wäre schlechter.

**Kein Bedarf ohne Regelung.** Wärmebedarf meldet ein Verteiler nur für Kreise, die auch geregelt
werden — Raum eingeschaltet und Messwert vorhanden. Ein Ventil, das offen steht, weil es niemand
zufährt, ist kein Abnehmer; sonst ließe es die Umwälzpumpe im Sommer durchlaufen. Von Hand
geöffnete Ventile zählen weiterhin, das ist eine Absicht.

**Kreise ohne Raum fahren zu.** Ein Kreis, der keinem Raum zugeordnet ist, hat niemanden, der ihn
anfährt — nach dem ersten Start steht er sogar auf Anschlag offen, weil unbekannte Stellungen
einmal angefahren werden. Einmal in der Minute wird deshalb geprüft, ob ein solcher Kreis offen
steht, und er wird zugefahren. Wer einen Kreis absichtlich offen halten will, hält ihn über die
Handsteuerung; Handbetrieb, Messfahrt und Schutzfahrt bleiben unangetastet.

### Einen einzelnen Kreis von Hand fahren

Unter **Kreise** steht ganz oben die Handsteuerung. Wählen Sie den Kreis und fahren Sie mit
**Motor auf**, **Motor aus**, **Motor zu**.

Kreise

Die Handsteuerung wirkt **unabhängig von der Stellung, die die Firmware für richtig hält**. Das
ist der Notfall-Weg: Wenn die geschätzte Stellung nicht zur Wirklichkeit passt, fährt der Motor
trotzdem in die gewünschte Richtung, bis die Endlage erkannt wird oder die Maximallaufzeit
abläuft.

Ein von Hand gefahrener Kreis bleibt aus der Regelung genommen, bis Sie ihn mit **Wieder regeln**
freigeben. Die Übersicht weist das aus.

> **Betriebsregel:** Innerhalb einer Messgruppe fährt immer nur ein Kreis. Fordern Sie einen
> zweiten Kreis derselben Gruppe an, wartet er, bis der erste steht. Die Gruppen stehen unter
> **Kreise**.

### Pumpe von Hand

Auf dem Gerät am Pufferspeicher steht unter **Heizkreise** je Kreis ein Schalter mit drei
Stellungen:

| Stellung | Wirkung |
|---|---|
| **Automatik** | Die Pumpe folgt dem Bedarf der zugeordneten Verteiler |
| **Ein** | Die Pumpe läuft dauerhaft |
| **Aus** | Die Pumpe steht dauerhaft |

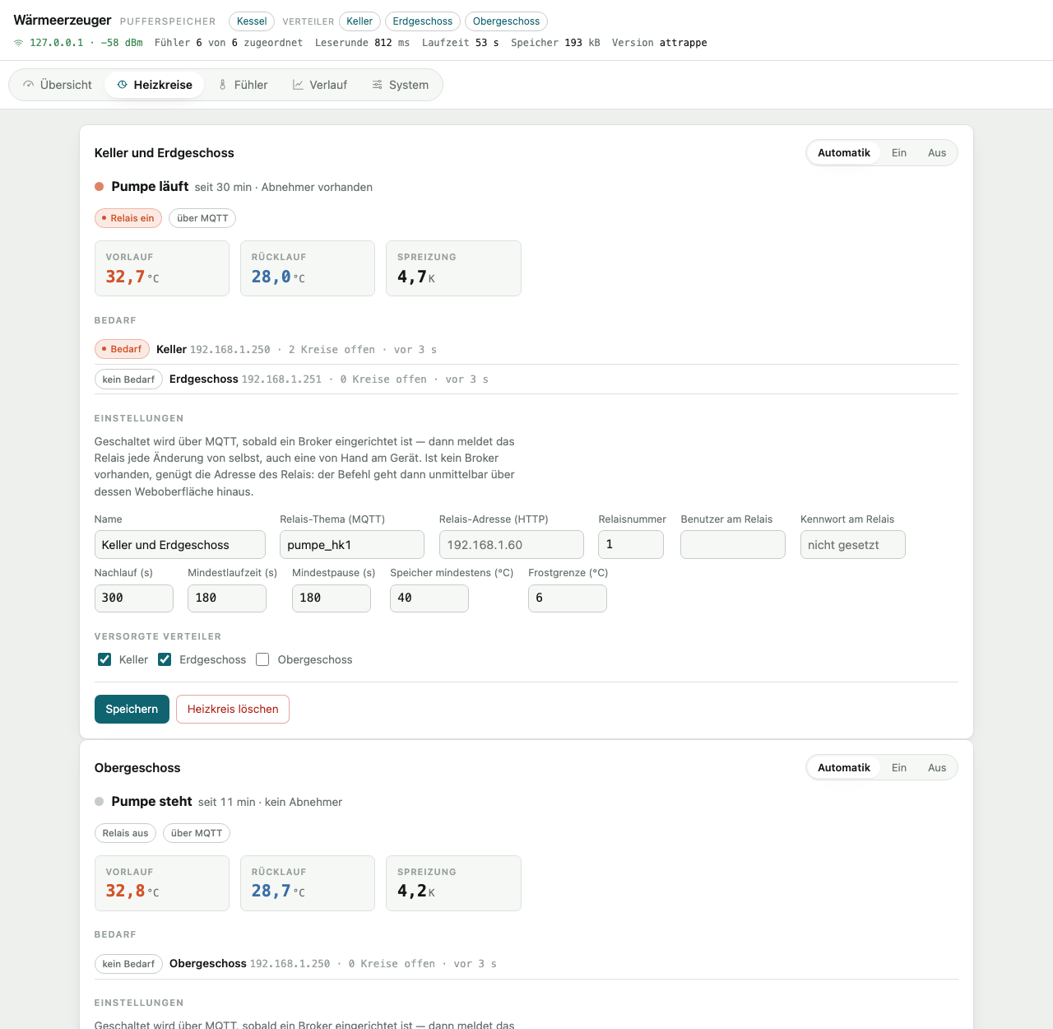
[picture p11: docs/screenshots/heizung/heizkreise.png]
Heizkreise


Der Wechsel wirkt sofort; Mindestlaufzeit und Mindestpause werden dabei übergangen. Der
Frostschutz geht auch der Stellung **Aus** vor: fällt eine Raumtemperatur unter die Frostgrenze,
läuft die Pumpe.

## Räume einrichten

Unter **Räume** legen Sie an, welche Heizkreise zu welchem Raum gehören und welches Thermometer
seine Temperatur liefert.

Räume

| Angabe | Bedeutung |
|---|---|
| Name | erscheint auf der Übersicht, am Gerät und in Home Assistant |
| Heizkreise | ein Kreis gehört zu höchstens einem Raum; Kreise ohne Raum werden zugefahren, siehe oben |
| Thermometer | eines der empfangenen Geräte, siehe unten |
| Sollwert | Zieltemperatur |
| Proportionalband | Abweichung vom Sollwert, bei der der Kreis ganz auf (darunter) oder ganz zu (darüber) steht; am Sollwert steht er halb offen. Vorgabe 1 K |
| Prüfintervall | wie oft die Regelung nachsteuert; Vorgabe 30 s |
| Rasterung | Schrittweite der Zielstellung; Vorgabe 0,1 |

**Ohne zugeordnetes Thermometer wird nicht geregelt.** Der Raum erscheint dann mit dem Hinweis
„kein Thermometer" und die Ventile bleiben stehen. Dasselbe gilt, wenn ein Messwert länger
ausbleibt als die eingestellte Zeitgrenze — die Regelung rechnet dann nicht mit einem veralteten
Wert weiter.

### Thermometer

Unter **Sensoren** stehen alle in Reichweite empfangenen Geräte: Xiaomi-Thermometer mit ATC- oder
pvvx-Firmware, RuuviTags und Thermometer, die BTHome senden. Sie senden ihre Messwerte als
Rundruf; das Gerät hört nur mit.

Sensoren

Trägt ein Thermometer einen Namen, steht er in der ersten Spalte über der Adresse. Bei der
pvvx-Firmware lässt sich der Name frei setzen, was die Zuordnung erheblich erleichtert. Die Namen
kommen erst auf Nachfrage vom Thermometer, deshalb erscheinen sie einige Sekunden nach dem
ersten Messwert.

#### Verschlüsselte Thermometer

Der Climate-Sat von camperSense sendet BTHome in Fassung 2 verschlüsselt mit AES-128-CCM. Jedes
Gerät hat einen eigenen Schlüssel aus 32 Hexadezimalziffern; die camperSense-App zeigt ihn beim
jeweiligen Sensor an. Ohne Schlüssel erscheint das Thermometer unter **Sensoren** mit Adresse und
Empfang, aber ohne Messwerte und mit dem Hinweis „Schlüssel fehlt".

Eingetragen wird der Schlüssel unter **Sensoren → Schlüssel verschlüsselter Thermometer**, in der
App unter **Geräte → Verteiler → Sensoren** durch Antippen des Thermometers. Leerzeichen und
Bindestriche in der Eingabe werden übergangen. Mit dem nächsten Rundruf, beim Climate-Sat nach
etwa zwei Sekunden, erscheinen die Werte; passt der Schlüssel nicht, steht dort „Schlüssel
falsch". Zugeordnet wird das Thermometer danach wie jedes andere, einem Raum oder als
Außenfühler.

- Ein Verteiler speichert bis zu 16 Schlüssel, in einem eigenen Speicherbereich und nicht in der
  Konfiguration. `GET /api/config` zeigt sie nicht, `GET /api/ble` nennt nur die Adressen, für die
  einer hinterlegt ist. Im Klartext stehen sie allein in der Sicherung.
- Jeder Rahmen trägt einen Zähler. Angenommen wird nur ein höherer als der zuletzt angenommene;
  ein aufgezeichneter und später erneut gesendeter Rahmen bleibt damit ohne Wirkung. Springt der
  Zähler zurück, etwa weil der Speicher des Satelliten gelöscht wurde, gilt er nach zehn Minuten
  ohne gültigen Rahmen wieder.
- Der Climate-Sat mit Lagesensor sendet abwechselnd einen Rahmen mit Temperatur und einen mit der
  Neigung. Der Verteiler übernimmt die Werte feldweise. Das Alter des Raummesswerts setzt nur ein
  Rahmen mit Temperatur zurück.
- Offen gesendetes BTHome, etwa von der pvvx-Firmware in dieser Betriebsart, braucht keinen
  Schlüssel.

## Heizkreise und Messfahrt

Unter **Kreise** stehen je Kreis die Fahrzeiten und die Auslöseschwelle der Endlagenerkennung.

Die Antriebe haben keine Endschalter. Die Endlage wird daran erkannt, dass der Motor am Anschlag
blockiert und die Spannung über dem Messwiderstand steigt. Wie hoch diese Spannung ausfällt und
wie lange ein Kreis von zu nach auf braucht, ist von Antrieb zu Antrieb verschieden.

### Messfahrt

Die Messfahrt ermittelt beides selbst. Sie fährt den Kreis einmal ganz zu und einmal ganz auf,
zeichnet die Spannung im 50-Millisekunden-Raster auf und leitet daraus Fahrzeiten und Schwelle
ab.

Messfahrt

1. **Kreise** öffnen, beim gewünschten Kreis **Messfahrt starten**.
2. Der Verlauf wird währenddessen gezeichnet. Eine Fahrt dauert rund anderthalb Minuten.
3. Nach dem Ende stehen die Vorschläge unter dem Diagramm. **Übernehmen** schreibt sie in die
   Konfiguration, **Verwerfen** lässt alles beim Alten.

Während einer Messfahrt ist die Messgruppe des Kreises belegt; andere Kreise derselben Gruppe
warten.

> Die Messfahrt lohnt sich. An der bestehenden Anlage lagen die gemessenen Fahrzeiten
> durchgehend unter den zuvor fest eingestellten Werten — die Kreise waren damit systematisch
> anders eingestellt, als angenommen.

### Abstand zum Anschlag auf

Gewöhnliche Fahrten öffnen höchstens bis 92 % des Hubs; Ziele darüber werden auf 92 % begrenzt.
Ein ganz geöffneter Kreis steht deshalb bei 92 %. Die Fahrzeit auf aus der Messfahrt reicht bis
zum Anschlag auf. Dort fängt ein Steg am Zahnrad den Nippel des Stößels ab, und das
Blockiermoment des Getriebes geht in die Stößelführung — beim HmIP-VDMOT das Teil, das am
häufigsten bricht. Das Ventil steht vor dem Anschlag bereits ganz offen.

In den Anschlag auf fahren nur noch die Notfahrt (**Motor auf** in der Handsteuerung, **Auf** in
der Kreistabelle, **Alle auf**, MQTT `OPEN`) und die Messfahrt. In Richtung zu nimmt der
Ventilsitz den Druck auf.

### Entlastung nach dem Schließen

Zu fährt ein Kreis, bis der Motor am Ventilsitz blockiert. Die Spindel des Antriebs ist
selbsthemmend; nach dem Abschalten bliebe die volle Blockierkraft deshalb auf Ventilstift und
Dichtung stehen, im Sommer über Monate. Nach jeder Fahrt zu, die an der Endlage oder an der
Maximallaufzeit endet, fährt der Antrieb daher eine Sekunde wieder auf. Das sind bei rund 40 s
für den ganzen Hub etwa 0,1 mm, von denen das Spiel im Getriebe einen Teil aufnimmt. Die Kraft
ist danach weitgehend abgebaut, das Ventil bleibt geschlossen; die Feder des Ventils hält den
Stift am Stößel. Die Stellung bleibt bei 0 %, als Grund der letzten Fahrt bleibt „Endlage
erkannt“ beziehungsweise „Maximallaufzeit abgelaufen“ stehen.

Folgt auf eine Referenzfahrt unmittelbar eine Fahrt auf, entfällt die Entlastung. Bleibt ein
Raum nach dem Schließen spürbar warm, ist die Entlastung für dieses Ventil zu lang.

## Fühler des Heizungsgeräts zuordnen

Ein DS18B20 meldet sich mit seiner Werkskennung, nicht mit seiner Einbaulage. Unter **Fühler**
ordnen Sie jeder Kennung ihre Rolle zu.

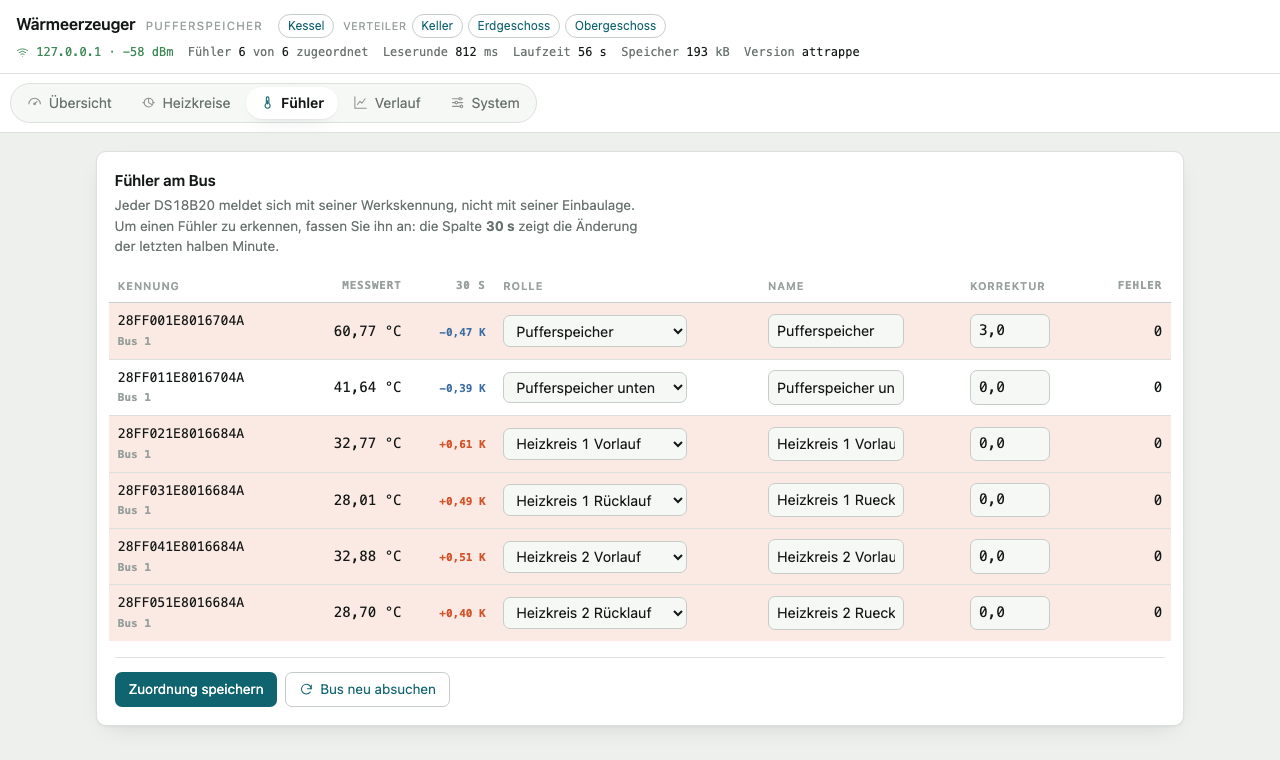
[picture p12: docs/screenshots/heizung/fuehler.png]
Fühler


**So finden Sie den richtigen:** Fassen Sie einen Fühler mit der Hand an. Die Spalte **30 s**
zeigt die Änderung der letzten halben Minute; die betroffene Zeile hebt sich sichtbar hervor.
Ordnen Sie ihn dann zu und speichern Sie.

| Rolle | Wo der Fühler sitzt |
|---|---|
| `abgas` | außen am Abgasrohr des Kessels |
| `kessel_vl`, `kessel_rl` | Vor- und Rücklauf des Kessels |
| `puffer` | Pufferspeicher |
| `puffer_unten` | unterer Bereich des Speichers, sofern vorhanden |
| `hk<n>_vl`, `hk<n>_rl` | Vor- und Rücklauf des Heizkreises n, hinter dem Mischer |
| `aussen` | Außentemperatur; kommt vom RuuviTag an der Verteilerplatine und lässt sich hier nicht zuordnen |

**Korrekturwert.** Sitzt ein Fühler nicht ganz an der richtigen Stelle, tragen Sie die Abweichung
in Kelvin ein; sie wird auf jeden Messwert addiert. Anzumerken ist, dass ein fester Korrekturwert
eine Abweichung nur an einem Betriebspunkt ausgleicht: bei einem geschichteten Speicher ändert
sich der Fehler mit dem Ladezustand.

**Fehlerzähler.** Die letzte Spalte zählt verworfene Messungen. Der Wert 85,0 °C ist der
Einschaltwert eines DS18B20 nach einem Spannungseinbruch, −127 °C zeigt eine unterbrochene
Leitung an. Beide werden verworfen; steigt der Zähler stetig, stimmt etwas mit der Verkabelung
nicht.

### Anschluss des Busses

Der 1-Wire-Bus hängt an einem frei wählbaren Anschluss und braucht einen Anschlusswiderstand
**nach 3,3 V** — einen je Bus, am Gerät, nicht am Fühler.

| Leitungslänge | Widerstand | Kabel |
|---|---|---|
| bis etwa 10 m | 4,7 kΩ | beliebig |
| 10 bis 50 m | 2,2 bis 3,3 kΩ | verdrillt, DQ mit GND als Paar |
| darüber | eigener 1-Wire-Treiber vorsehen | verdrillt und geschirmt |

Bei langer Leitung begrenzt nicht der Spannungsabfall, sondern die Kapazität der Leitung: Sie
macht die steigende Flanke träge. Dagegen hilft ein kleinerer Widerstand, keine höhere Spannung.
Drei Fühler ziehen zusammen rund 4,5 mA; auf 30 m Alarmkabel sind das etwa 20 mV Abfall.

Die Fühler werden mit **3,3 V** versorgt, nicht mit 5 V. Der Anschluss des ESP32 verträgt
höchstens 3,6 V, und mit 5 V am Fühler steigt dessen Erkennungsschwelle über den Pegel, den ein
Widerstand nach 3,3 V erzeugt — die Kombination aus 5 V am Fühler und 3,3 V am Widerstand
schweigt deshalb, und die umgekehrte belastet den Anschluss über seinen Grenzwert.

Versorgt werden die Fühler regulär über VDD, nicht parasitär: Die Firmware startet die Messung
mit einem Sammelbefehl an alle Fühler zugleich, und dafür reicht der Strom aus der Datenleitung
nicht. Die Wahl steht im Einrichtungsassistenten und später unter
**System → 1-Wire-Bus**; eine Änderung wirkt sofort, ein Neustart ist nicht nötig.

| Anschluss | Geeignet |
|---|---|
| 13, 14, 16 bis 19, 21 bis 23, 25 bis 27, 32, 33 | ja — freie Anschlüsse ohne Sonderaufgabe |
| 6 bis 11 | nein, sie gehören zum Flash-Speicher |
| 34 bis 39 | nein, nur als Eingang ausgelegt und damit nicht treibfähig |
| 1 und 3 | nein, das ist die serielle Schnittstelle |
| 12 | nein, entscheidet beim Start über die Flash-Spannung; der Anschlusswiderstand verhindert den Start |
| 0, 2, 15 | möglich, aber ungünstig — sie werden beim Start ausgewertet |

Die Firmware lehnt die ungeeigneten Anschlüsse mit Begründung ab. Im Assistenten zeigt die
Seite laufend, wie viele Fühler sich am eingetragenen Anschluss melden; nach dem Umstellen
dauert es bis zu einer Minute, bis der Bus neu abgesucht ist.

## Pumpen einrichten

Auf dem Gerät am Pufferspeicher legen Sie unter **Heizkreise** an, welche Verteiler ein Kreis
versorgt und über welches Relais seine Pumpe geschaltet wird. Vorgesehen sind bis zu vier Kreise.

Die Schaltfläche **Heizkreis anlegen** steht am Ende der Seite und nennt, wie viele Kreise
bereits angelegt sind. Jeder neue Kreis bekommt die nächste freie Kennung und damit die
Fühlerrollen „Vorlauf Heizkreis n" und „Rücklauf Heizkreis n"; ordnen Sie ihm anschließend unter
**Fühler** die beiden Messstellen zu. Über **Heizkreis löschen** am Fuß einer Karte entfällt ein
Kreis wieder. Seine Pumpe wird dabei einmal abgeschaltet — sonst liefe sie weiter, ohne dass sie
noch jemand steuert. Die zugeordneten Fühler bleiben stehen, die übrigen Kreise behalten ihre
Kennung und ihre Einstellungen.

| Angabe | Bedeutung |
|---|---|
| Name | erscheint in der Oberfläche und in Home Assistant |
| Relais-Thema (MQTT) | Tasmota-Thema, etwa `pumpe_hk1` |
| Relais-Adresse (HTTP) | Adresse des Relais, falls kein Broker vorhanden ist |
| Relaisnummer | 1 bis 8, bei mehrkanaligen Geräten |
| Benutzer, Kennwort | nur wenn das Relais eine Anmeldung verlangt |
| Nachlauf | wie lange die Pumpe nach dem letzten Bedarf weiterläuft; Vorgabe 300 s |
| Mindestlaufzeit, Mindestpause | verhindern kurzes Takten; je 180 s |
| Speicher mindestens | darunter bringt Umwälzen nichts; Vorgabe 40 °C |
| Frostgrenze | darunter läuft die Pumpe in jedem Fall; Vorgabe 6 °C |
| Versorgte Verteiler | welche Platinen den Bedarf dieses Kreises melden |

**Zu den beiden Wegen.** Ist ein Broker eingerichtet und die Verbindung steht, geht der Befehl
über MQTT — dann meldet das Relais jede Änderung von selbst, auch eine von Hand am Gerät. Sonst
genügt die Adresse: der Befehl geht unmittelbar an die Schnittstelle `/cm` des Relais. Zwischen
zwei Aufrufen bleibt eine Änderung am Relais dabei unbemerkt, deshalb wird der Sollzustand alle
sechzig Sekunden nachgesendet. Die Oberfläche weist aus, welcher Weg gerade gilt.

**Warum „Speicher mindestens" hoch liegt.** Der Mischer kann nur herunterregeln. Fällt der
Speicher unter die benötigte Vorlauftemperatur, öffnet der Mischer vollständig und der Kreis
bekommt trotzdem zu wenig. Der Wert gehört deshalb **über** die höchste benötigte
Fußbodenvorlauftemperatur, nicht knapp über Raumtemperatur.

### Was bei einer Störung geschieht

| Fall | Verhalten |
|---|---|
| Ein zugeordneter Verteiler antwortet nicht mehr | Bedarf gilt als vorhanden, die Pumpe läuft; die Oberfläche meldet „Verteiler antwortet nicht" |
| Ein Verteiler hat seit dem Start nie geantwortet | Er wird nicht gewertet — sonst liefe die Pumpe wegen eines abgeschalteten Geräts durchgehend |
| Ein offenes Ventil gehört zu einem Raum ohne Messwert | Es zählt nicht als Bedarf; die Meldung des Verteilers weist es getrennt aus („ohne Regelung") |
| Ein Ventil gehört zu keinem Raum | Es zählt nicht als Bedarf und wird zugefahren |
| Diese Steuerung fällt ganz aus | Am Relais sorgt eine Regel dafür, dass die Pumpe von selbst anläuft (siehe unten) |
| Die Rückmeldung weicht länger als 30 s vom Sollwert ab | „Relais folgt nicht" |
| Das Relais nimmt keine Verbindung an | Es gilt als stromlos: Die vorgeschaltete Regelung hat den Pumpenausgang abgeschaltet (siehe unten). Die Pumpe gilt als stehend, keine Störung; die Vertauschungsprüfung ruht |
| Das Relais ist stromlos, die Steuerung will die Pumpe aber laufen lassen | „vorgeschaltete Regelung gibt die Pumpe nicht frei"; die App meldet es nach einer Stunde als Hinweis |
| Die Pumpe läuft, im Kreis fließt aber kaum Wasser | Die App meldet nach einer halben Stunde „Die Pumpe läuft, die Wärme kommt nicht an“, siehe unten |

**Kein Durchfluss trotz laufender Pumpe.** Steckt Luft in der Leitung, dreht die Pumpe, ohne
Wasser in das obere Geschoss zu fördern; die Fühler am Heizungsgerät zeigen dann nur, was sich
nahe am Mischer erwärmt. Die App erkennt das auf zwei Wegen. Trägt einer der versorgten Verteiler
einen Fühler am 1-Wire-Bus, gilt dessen wärmster Wert als Vorlauf am Verteiler: Liegt der Vorlauf
am Heizungsgerät mindestens 10 K darüber, kommt nichts an (Warnung). Ohne solchen Fühler bleibt
ein Hinweis: Rücklauf mindestens 14 K über dem Mittel der beheizten Räume bei höchstens 6 K
Spreizung. Mit Durchfluss kühlt das Wasser in den Schleifen deutlich stärker ab; an dieser Anlage
lag der Rücklauf dann 6 bis 8 K über den Räumen, mit Luft in der Leitung 16 K. Beide Meldungen
erscheinen erst, wenn der Zustand eine halbe Stunde anhält, und nur, solange Vorlauf mindestens
10 K über den Räumen liegt. Ein Fühler am Vorlauf jedes Verteilers macht die Prüfung eindeutig.

Häufigste Ursache ist zu niedriger Anlagendruck: Am höchsten Punkt müssen mindestens 0,3 bis
0,5 bar anliegen, am Kessel also je Meter Höhe 0,1 bar mehr. Reicht er nicht, saugt ein geöffneter
Entlüfter Luft an, statt sie abzulassen. Entlüftet wird deshalb nur bei warmer Anlage und
ausreichendem Druck.

**Absicherung am Relais.** Das Gerät sendet alle sechzig Sekunden ein Lebenszeichen. Hinterlegen
Sie am Tasmota-Relais folgende Einstellungen, damit die Pumpe bei einem Ausfall dieser Steuerung
von selbst anläuft:

```
PowerOnState 1
Rule1 ON Var1#State DO RuleTimer1 900 ENDON ON Rules#Timer=1 DO Power1 1 ENDON
Rule1 1
```

Bleibt das Lebenszeichen aus, schaltet das Relais nach einer Viertelstunde ein. Eine laufende
Pumpe gegen geschlossene Ventile ist verschwenderisch, aber unschädlich; eine stehende Pumpe bei
Wärmebedarf ist es nicht.

**Relais hinter einer vorgeschalteten Regelung.** Häufig bleibt die bisherige Regelung im Spiel:
Das Tasmota-Relais hängt am Pumpenausgang der Kesselregelung (Heizkreise) oder des Heliomaten
(Ladepumpe), und die Pumpe läuft nur, wenn beide sie wollen. Schaltet die vorgeschaltete Regelung
ab, hat das Relais keinen Strom und verschwindet aus dem Netz. Das Heizungsgerät wertet eine
fehlende Verbindung deshalb nicht als Störung, sondern als **stromlos**: Die Pumpe gilt als
stehend, die Oberfläche zeigt „Relais ohne Strom“ mit der Dauer, und eine Abweichung zwischen
Sollzustand und letzter Rückmeldung wird in dieser Zeit nicht gemeldet. Bekommt das Relais wieder
Strom, erhält es binnen zehn Sekunden den Sollzustand. Antwortet es dagegen mit einem falschen
Status, steht die Verbindung, und es bleibt eine Störung.

Damit eine Pumpe sofort läuft, sobald die vorgeschaltete Regelung Strom gibt, gehört an jedes
solche Relais `PowerOnState 1`; die Steuerung schaltet sie gegebenenfalls kurz danach ab. An der
Kesselkreispumpe ist das wichtig: Startet das Relais dort ausgeschaltet, heizt der Kessel ohne
Abfuhr, bis die Brennererkennung anspricht.

Will die Steuerung eine Pumpe laufen lassen, während ihr Relais stromlos ist, gilt der Kreis als
**gesperrt**, etwa in der Nachtabsenkung der Kesselregelung. Soll diese Steuerung allein über die
Heizkreispumpen entscheiden, gehören deren Ausgänge an der Kesselregelung auf Dauerbetrieb.

## Brenner und Pufferspeicher

Sind die entsprechenden Fühler zugeordnet, erscheinen auf der **Übersicht** zwei weitere Karten.

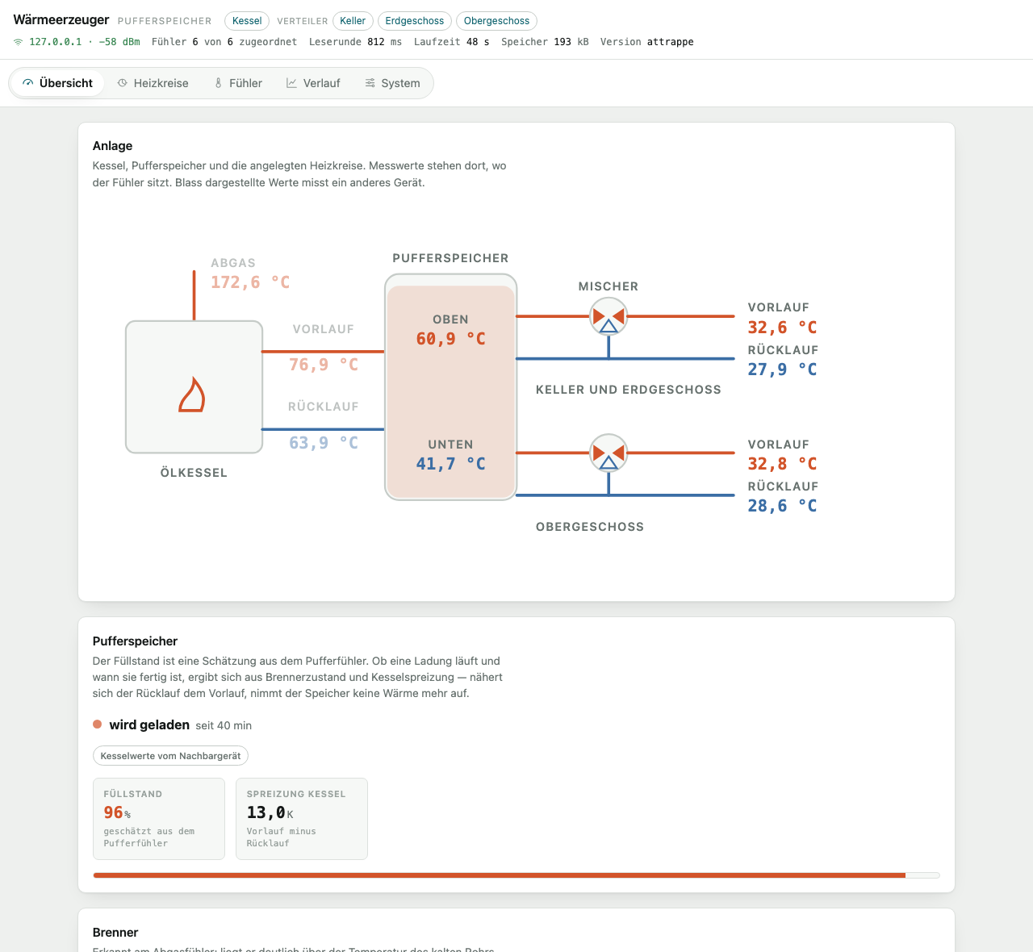
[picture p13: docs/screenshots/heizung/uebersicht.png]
Übersicht des Heizungsgeräts


### Brenner

Erkannt wird am Abgasfühler. Ein fester Schwellwert wäre von der Raumtemperatur des Heizungsraums
abhängig — im Sommer stünde er zu tief, im Winter zu hoch. Gemessen wird deshalb gegen eine
gleitende Bezugslinie: das Minimum der letzten 24 Stunden, also die Temperatur des kalten Rohrs.

| Angabe | Vorgabe | Bedeutung |
|---|---|---|
| Einschaltschwelle | 12 K | so weit über dem kalten Rohr gilt der Brenner als laufend |
| Ausschaltschwelle | 6 K | darunter als aus |
| Haltezeit ein | 60 s | so lange muss die Bedingung anhalten |
| Haltezeit aus | 300 s | länger, damit kurzes Abkühlen den Lauf nicht beendet |
| Düsendurchsatz | 2,2 l/h | Grundlage der Verbrauchsschätzung — **siehe unten** |

Laufzeit und Starts des Tages überdauern einen Neustart. Häufige kurze Starts bei geringer
Gesamtlaufzeit werden als **Taktbetrieb** ausgewiesen — der Kessel geht dann öfter an, als er
Wärme abgibt.

**Der Ölverbrauch ist eine Schätzung**, keine Messung: Laufzeit mal Düsendurchsatz. Die Laufzeit
ist gemessen, der Durchsatz nicht — der Vorgabewert von 2,2 l/h ist ein plausibler Wert für eine
kleine Öldüse (rund 0,60 gph), er stammt nicht von Ihrer Anlage. Alle Literangaben in Tages- und
Ladungsprotokoll sowie in der Verbrauchslinie sind ihm unmittelbar proportional:

| Düse | Verbrauch an einem Tag mit 45 min Laufzeit |
|---|---|
| 1,60 l/h | 1,20 l |
| 1,89 l/h (0,50 gph) | 1,42 l |
| 2,20 l/h (Vorgabe) | 1,65 l |
| 2,65 l/h (0,70 gph) | 1,99 l |
| 3,00 l/h | 2,25 l |

Zwei Wege zum richtigen Wert. **Ablesen:** Die Größe steht auf der Düse selbst und meist in den
Unterlagen des Brenners, in gph — 0,50 gph sind 1,89 l/h, 0,60 gph sind 2,27 l/h. Das ist der
Nenndurchsatz bei Prüfdruck; weicht der eingestellte Pumpendruck davon ab, verschiebt sich der
Wert. **Messen:** Lesen Sie den Tankfüllstand zweimal im Abstand einiger Monate ab und teilen Sie
die verbrauchte Menge durch die summierte Brennerlaufzeit aus dem Tagesprotokoll. Das ergibt den
tatsächlichen Durchsatz einschließlich Pumpendruck und Düsenverschleiß — und macht aus der
Schätzung rückwirkend eine Messung.

### Ladezustand

Der Füllstand ist eine lineare Schätzung aus dem Pufferfühler zwischen den Werten für „leer" und
„voll". Ob eine Ladung läuft und wann sie fertig ist, ergibt sich aus zwei Beobachtungen:

- Während der Ladung ist der Kesselrücklauf kalt. Nähert er sich dem Vorlauf und bleibt fünf
  Minuten dort, nimmt der Speicher keine Wärme mehr auf.
- Schaltet der Brenner bei hohem Vorlauf von selbst ab, hat die eigene Regelung des Kessels die
  Ladung für beendet erklärt.

Stehen Kessel und Speicher an verschiedenen Geräten, holt sich das Gerät am Speicher die
Kesselwerte vom Nachbargerät. Bleiben sie aus, fällt die Beurteilung auf den Pufferfühler allein
zurück und meldet das als **„nur Schätzung, Kesselwerte fehlen"**.

Fällt der Pufferwert unter die Warnschwelle, erscheint **„Warmwasserreserve knapp"**. Da das
Trinkwasser im Durchlauf erwärmt wird, ist das der praktisch spürbare Grenzfall.

> Die Vorgabewerte (8 K Spreizung, 62 °C voll, 35 °C leer, Warnung unter 40 °C) sind Annahmen.
> Ziehen Sie sie nach der ersten aufgezeichneten Ladung nach.

### Außenfühler

Ein RuuviTag oder ein Thermometer mit BTHome, etwa der Climate-Sat von camperSense, kann als
Außenfühler dienen. Er gehört zu keinem Raum: Seine Temperatur geht in keine Ventilstellung ein,
sondern wird aufgezeichnet und an die Heizungsgeräte weitergereicht, damit sich Verbrauch und
Wetterlage später gegenüberstellen lassen.

Zugeordnet wird er an einer Verteilerplatine unter **Sensoren → Außenfühler** oder am
[Leitstand](#leitstand) unter **Funk**. Die Temperatur steht danach in der Kopfzeile, in Home
Assistant und im Verlauf der Heizungsgeräte. Ein RuuviTag liefert zusätzlich Luftfeuchtigkeit und
Luftdruck.

Warum an der Verteilerplatine und nicht am Heizungsgerät: Die Heizungsgeräte haben kein
Bluetooth — dort sitzen die Fühler am 1-Wire-Bus. Die Verteilerplatinen hören ohnehin mit, weil
sie die Raumthermometer empfangen.

Jedes Heizungsgerät holt sich den Wert einmal je Minute selbst: zuerst beim Leitstand, sonst bei
der ersten Verteilerplatine, die einen liefert. Es genügt also **ein** Gerät im Haus mit
Außenfühler, und eine Verteilerplatine muss dafür keinem Heizkreis zugeordnet sein. Unter
**Anlage** steht, von welchem Gerät der Wert kommt. Eine Außentemperatur ist eine Größe des
Hauses, keine eines Heizkreises. Heizungsgeräte bis 0.4.0 kennen den Leitstand noch nicht und
fragen nur die Verteilerplatinen.

Bleibt das Thermometer länger als eine Viertelstunde stumm, gilt sein Wert als veraltet und wird
nicht mehr weitergegeben — sonst schriebe eine leere Batterie eine eingefrorene Temperatur in
die Heizgradtage, ohne dass es auffiele. Die Verteilerplatine zeigt dann **kein Messwert** statt
des letzten Werts.

Unter den Verteilerplatinen sollte **nur eine** einen Außenfühler tragen. Melden zwei einen Wert,
nimmt das Heizungsgerät den zuletzt eingegangenen; die Temperatur wechselte dann zwischen zwei
Quellen. Ein Leitstand geht den Verteilerplatinen vor, solange sein Wert frisch ist; eine
Verteilerplatine mit Außenfühler bleibt dann Ersatz für den Fall, dass er ausfällt.

#### Funkbrücke: eine Platine nur für den Empfang

Steht das Thermometer außerhalb der Reichweite aller Verteilerplatinen, etwa am Kessel, genügt
eine weitere Platine mit der Verteiler-Firmware in seiner Nähe. Mit einem [Leitstand](#leitstand)
entfällt sie: Er empfängt die Thermometer selbst. Sie braucht keine Ventile, keine
Räume und keinen Heizkreis: Ein handelsüblicher ESP32 reicht, die Firmware kommt über den
Web-Flasher darauf.

1. Firmware aufspielen, das Gerät über seinen Einrichtungs-Zugangspunkt ins WLAN bringen.
2. Im Einrichtungsassistenten die Aufgabe **Nur Außenfühler** wählen und dem Gerät einen Ort
   geben, etwa „Funkbrücke Kessel“. Ein bereits eingerichtetes Gerät wird über
   **System → Einrichtung erneut durchlaufen** umgestellt; seine Räume entfallen dabei.
3. Im zweiten Schritt das Thermometer als Außenfühler wählen. Sendet es verschlüsselt, zuerst
   unter **Sensoren** den Schlüssel hinterlegen.
4. Den Außenfühler an der bisherigen Platine abmelden, damit nur eine Quelle meldet.

In dieser Betriebsart rührt die Platine keinen Kanal an: keine Schutzfahrt, kein Anfahren
unbekannter Stellungen, keine Messfahrt, keine Fahrbefehle. Die Oberfläche zeigt statt Räumen und
Kreisen den Außenfühler, die Anzeige am Gerät seine Temperatur, und Home Assistant erhält keine
Ventile. `GET /api/state` meldet unter `device.function` den Wert `outdoor`, sonst `valves`.

Die Heizungsgeräte finden die Brücke über mDNS und holen den Wert wie von jeder anderen Platine.
Ohne Räume meldet sie keinen Wärmebedarf, braucht keinen Heizkreis, und die App führt sie nicht
unter den Räumen. Ein Leitstand, der das Thermometer selbst nicht empfängt, übernimmt den Wert
der Brücke, siehe [Funkthermometer und Außenfühler](#funkthermometer-und-außenfühler).

### Brennerzustand am Pufferspeicher

Das Gerät am Pufferspeicher hat keinen Abgasfühler — der sitzt am Kessel. Es zeigt den
Brennerzustand trotzdem an, mit der Marke **vom Gerät am Kessel**, sobald jenes im Netz ist.
Laufzeit, Starts und Verbrauch bleiben dort, wo gemessen wird; hier steht nur, ob der Brenner
gerade läuft. Danach richten sich Ladezustand und Aufzeichnung.

Ohne erreichbares Gerät am Kessel steht dort **kein Abgasfühler**, und die Aufzeichnung weicht
auf die Speichertemperatur aus.

### Einstellungen im Einzelnen

Alle Werte stehen in der Oberfläche des jeweiligen Heizungsgeräts. Was hier nicht steht, ist
entweder eine Messung oder eine Angabe zur Verdrahtung.

**Brenner** (Karte *Brenner*, Bereich Übersicht)

| Feld | Vorgabe | Bedeutung |
|---|---|---|
| Ein ab (K über der Linie) | 12 K | So weit muss das Abgas über der Bezugslinie liegen, damit ein Anlauf erkannt wird. Zu klein: Ein warmer Aufstellraum löst aus. Zu groß: Ein kurzer Start bleibt unbemerkt. |
| Aus unter (K) | 6 K | Fällt das Abgas so weit an die Bezugslinie heran, gilt der Brenner als aus. Greift nur bei kaltem Kessel; bei warmem entscheidet der Ausschlag. |
| Ausschlag (K) | 6 K | Fällt das Abgas so weit unter den Höchstwert der laufenden Fahrt, ist der Brenner aus; steigt es danach so weit über den Tiefstwert, läuft er wieder. Dies ist das eigentliche Kriterium — die Bezugslinie beschreibt das kalte Rohr und versagt, solange der Kessel warm ist. Zu klein: Ein Messrauschen beendet die Fahrt. Zu groß: Kurze Takte verschmelzen zu einer Fahrt. |
| Haltezeit ein | 60 s | So lange muss die Einschaltbedingung anliegen. |
| Haltezeit aus | 300 s | Länger, damit kurzes Abkühlen den Lauf nicht beendet. |
| Düsendurchsatz | 2,2 l/h | Siehe oben — der einzige Wert, den Sie an Ihrer Anlage nachschlagen sollten. |

**Pufferspeicher** (Karte *Pufferspeicher*)

| Feld | Vorgabe | Bedeutung |
|---|---|---|
| Speicherinhalt | 0 l | Nur zum Umrechnen entnommener Kelvin in Kilowattstunden. 0 lässt die Angabe in Kelvin stehen. Grob abzuschätzen aus einer Ladung: gelieferte Wärme geteilt durch den Temperaturhub des Speichers, beides steht im Ladungsprotokoll. |
| Zapfung ab Einbruch | 2,0 K | So steil muss der Speicher fallen, damit es als Warmwasserzapfung gilt. Der Stillstandsverlust schafft im Vorgabefenster rund 0,2 K, ein Vollbad 6,5 K. |
| im Fenster | 900 s | Zeitfenster, über das der Einbruch gemessen wird. |
| Leer bei | 35 °C | Nullpunkt des Füllstands: die Temperatur, bei welcher der Kessel von sich aus anläuft. Wird selbst nachgemessen, sofern eingeschaltet. |
| Voll bei | 62 °C | Hundert Prozent. Sinnvoll ist der Wert, den der Speicher am Ende einer Ladung tatsächlich erreicht — er steht nach jeder Ladung im Ladungsprotokoll. **Auf beiden Heizungsgeräten gleich eintragen**, sonst zeigen sie verschiedene Füllstände für denselben Speicher. |
| Leerpunkt selbst nachmessen | ein | Beim Anlaufen des Brenners wird der Nullpunkt zu 40 Prozent an den gemessenen Wert herangeführt. |
| Nachmessen ab Abfall | 3 K | So weit muss der Speicher seit seinem Höchststand gefallen sein, damit ein Brennerstart als Messpunkt zählt. Verhindert, dass taktender Betrieb den Nullpunkt nach oben zieht. |
| Spreizung „voll" | 8 K | Nähert sich der Kesselrücklauf dem Vorlauf so weit an, nimmt der Speicher keine Wärme mehr auf. |
| Haltezeit | 300 s | So lange muss das anliegen. |
| Vorlauf gilt als heiß ab | 60 °C | Zusatzbedingung für „voll" und für die Frage, ob ein Abschalten des Brenners eine fertige Ladung war. Ohne sie gälte der kalte Anlauf als fertige Ladung — dort liegen Vor- und Rücklauf ebenfalls dicht beieinander, weil beide kalt sind. |
| Warnung Warmwasser | 40 °C | Darunter wird die Warmwasserreserve als knapp gemeldet. |

**Zeit und Neustart** (Bereich System)

| Feld | Vorgabe | Bedeutung |
|---|---|---|
| Zeitzone | `CET-1CEST,M3.5.0,M10.5.0/3` | Bestimmt, wann ein Tag im Protokoll endet und wann Termine fallen. |
| Neustart Stunde / Minute | −1 | Täglicher Neustart; −1 schaltet ihn ab. Er wird verschoben, solange eine Pumpe in einer Mindestlaufzeit steht. |
| Abfrage alle | 5 s | Wie oft die Verteiler nach Wärmebedarf gefragt werden. |
| Zeitgrenze | 180 s | Ab wann ein Verteiler, der einmal geantwortet hat und dann verstummt, als bedarfsmeldend gilt. |

### Kesselkreispumpe

Die Pumpe zwischen Kessel und Pufferspeicher wird am **Gerät am Kessel** eingerichtet, unter
**Heizkreise → Kesselkreispumpe**. Geschaltet wird sie wie die Heizkreispumpen über ein
Tasmota-Relais, über MQTT oder unmittelbar über HTTP.

Sie läuft, solange der Kessel Wärme abgibt, also sein Vorlauf wärmer ist als das Wasser, das aus
dem Speicher kommt. Kehrt sich das um, fördert dieselbe Pumpe Wärme aus dem Speicher in den
Kessel, und von dort geht sie durch den Schornstein verloren.

**Bei laufender Pumpe** wird der Kesselvorlauf mit dem Kesselrücklauf verglichen. Der Rücklauf
ist das Wasser, das tatsächlich aus dem Speicher kommt; die Differenz ist die Wärme, die der
Kessel gerade abgibt. Der Speicherfühler eignet sich dafür nicht, weil er an anderer Stelle sitzt.
An dieser Anlage lag er nach einer Ladung gut 3 K unter dem Rücklauf (Vorlauf 75,0 °C,
Rücklauf 75,3 °C, Speicher 72,0 °C). Gegen ihn gerechnet blieben 3 K „Abgabe“ stehen, die Pumpe
lief am 5. Oktober sieben Stunden durch, und der Kessel zündete in dieser Zeit sechsmal nach.

**Bei stehender Pumpe** fließt nichts: Vor- und Rücklauf nehmen beide die Temperatur des
Kesselkörpers an, und ihre Differenz sagt nichts mehr. Bezug ist dann die Speichertemperatur,
zuzüglich des Abstands, um den der Rücklauf beim letzten Lauf über dem Speicherfühler lag. Ohne
diesen Aufschlag liefe die Pumpe nach dem Abschalten gleich wieder an. Liegt der Rücklauf unter
dem Speicherfühler, etwa beim Entladen, gilt der Speicherfühler unverändert. Ohne
Speichertemperatur gilt auch bei stehender Pumpe der Rücklauf.

Beim Anlaufen des Brenners steht die Pumpe zunächst: Der kalte Kessel würde sonst den warmen
Speicher abkühlen. Sie springt an, sobald der Kesselvorlauf den Speicher um den Einschaltabstand
übersteigt — das ist zugleich die Rücklaufanhebung, die dem Kessel die Taupunktunterschreitung
erspart. Spätestens schaltet sie ein, wenn die Brennererkennung den Brenner meldet; das
geschieht je nach Abgasrohr eine bis mehrere Minuten nach dem Zünden.

| Einstellung | Vorgabe | Bedeutung |
|---|---|---|
| Ein ab Abstand | 3,0 K | So weit muss der Kesselvorlauf bei stehender Pumpe über dem Bezug liegen, damit sich das Fördern lohnt. |
| Aus unter | 2,0 K | Liegt der Kesselvorlauf bei laufender Pumpe weniger als diesen Abstand über dem Rücklauf, kommt nichts mehr an. Muss kleiner sein als „ein", sonst taktet die Pumpe. |
| Haltezeit | 120 s | so lange muss die Bedingung anliegen |
| Mindestlaufzeit, Mindestpause | je 180 s | verhindert Takten |
| Notgrenze | 85 °C | darüber läuft sie in jedem Fall |

Drei Regeln gehen der Spreizung vor. **Solange der Brenner läuft, läuft die Pumpe** — ohne
Haltezeit und auch in einer Mindestpause. Aus geht sie erst, wenn die Brennererkennung den
Brenner als aus meldet, und dann wie sonst nach Spreizung und Haltezeit; sie läuft also
mindestens die Haltezeit nach. Die Spreizung allein reicht dafür nicht aus: Am 23. September lag
der Kesselvorlauf während eines Brennerlaufs nur 0,9 K über dem Speicherfühler, die Pumpe stand,
und der Kessel schaltete den Brenner nach gut zwölf Minuten selbst ab. Ein Lauf dauert sonst rund
eine Dreiviertelstunde. **Ohne gültige Messwerte läuft die Pumpe** — eine laufende Pumpe ohne Not
ist verschwenderisch, ein heißer Kessel ohne Abfuhr ist es nicht. Und **überschreitet der
Kesselvorlauf die Notgrenze, läuft sie ebenfalls**, gleich was die Spreizung sagt; ein
klemmender Fühler darf die Wärmeabfuhr nicht verhindern. Bei stehender Pumpe erreicht die Wärme
des Kesselkörpers die Fühler am Rohr allerdings nur verzögert; die Notgrenze ersetzt deshalb die
Kopplung an den Brenner nicht.

**Nach einem Neustart** des Geräts beginnt die Regel bei laufender Pumpe, und aus geht sie
frühestens nach der Haltezeit. Die Brennererkennung setzt mit dem zuletzt gesicherten Zustand
fort: Lief der Brenner beim letzten Sichern und ist das Abgasrohr noch warm, gilt er weiter als
laufend, ohne dass ein zweiter Start gezählt wird. Gesichert wird bei jedem Wechsel und während
eines Laufs alle fünf Minuten.

Ein Klick auf das Pumpensymbol im Anlagenschema schaltet die Betriebsart weiter: Automatik,
Hand ein, Hand aus. **Hand aus** gilt auch bei laufendem Brenner und über der Notgrenze; die
Betriebsart ist für Arbeiten an der Pumpe gedacht, nicht für den Betrieb.

**Warum nur am Kessel.** Die Regelung braucht Kesselvor- und -rücklauf am selben Gerät. Mit
Werten vom Nachbargerät zu schalten wäre eine Entscheidung ohne eigene Grundlage — und schlimmer:
Fällt die Verbindung aus, gilt „keine Messwerte", und die Pumpe liefe dann dauerhaft. Die
Oberfläche bietet den Bereich deshalb nur dort an, und ein Einschalten ohne diese beiden Fühler
wird abgewiesen. Umgekehrt lassen sich Heizkreise nur auf dem Gerät mit dem Pufferfühler anlegen:
Ihre Freigabe hängt an der Speichertemperatur.

## Auswertung

Aus den beiden Protokollen rechnet das Gerät laufend einige Kennzahlen. Sie greifen **nicht** in
die Regelung ein — sie melden.

### Verbrauchslinie

Unter **Verlauf → Verbrauchslinie** wird eine Gerade durch die Tage im Protokoll gelegt:
Brennerlaufzeit über Heizgradtagen. Ein kalter Januar braucht mehr Öl als ein milder, ohne dass
an der Anlage etwas anders wäre; erst der Bezug auf die Außenlage macht Verbrauch vergleichbar.

- Die **Steigung** ist der Wärmebedarf des Hauses je Heizgradtag.
- Der **Achsenabschnitt** ist der Grundverbrauch ohne Heizbedarf, also Warmwasser.
- Die **Streuung** sagt, wie eng die Tage an der Linie liegen.

Ein Tag, der mehr als drei Streuungen über der Linie liegt, wird als Befund gemeldet. Das findet
ein Fenster, das offen steht; ein Ventil, das klemmt; eine Pumpe, die durchläuft. Nach unten wird
nie gemeldet: weniger Verbrauch ist kein Fehler.

Es braucht mindestens vierzehn Tage und eine Außenlage, die weit genug auseinanderliegt. Im
Sommer ist beides nicht gegeben — alle Tage stehen bei null Gradtagen, und durch eine senkrechte
Punktwolke führt keine sinnvolle Gerade. Die Karte nennt dann den Grund, statt eine Linie zu
zeigen, die keine ist. Tage ohne Außentemperatur bleiben außen vor und werden gezählt.

### Wärmepumpen-Check

Unter **Heizung › Auswertung › Wärmepumpen-Check** stellt die App zusammen, was die Planung einer
Wärmepumpe aus dem Betrieb der Ölheizung ablesen kann. Das ersetzt keine raumweise
Heizlastberechnung, ist aber ein Gegencheck aus dem tatsächlichen Verbrauch.

- **Heizlast:** Steigung der Verbrauchslinie mal Kesselleistung ergibt die Heizwärme je
  Heizgradtag; verlängert bis zur Normaußentemperatur des Orts (einstellbar, Vorgabe −12 °C) und
  durch 24 Stunden geteilt, die Heizlast in kW. Die Kesselleistung ist Düsendurchsatz mal Heizwert
  (10 kWh/l) mal Wirkungsgrad (einstellbar, Vorgabe 88 %). Dazu der Wärmeverlust des Hauses in W/K
  und die Brennerstunden, die der Auslegungstag bräuchte.
- **Warmwasser:** der Achsenabschnitt der Verbrauchslinie in kWh je Tag.
- **Heizlast aus der Speicherwärme:** unabhängig von Düse und Wirkungsgrad. Zwischen zwei Ladungen
  gibt der Speicher Wärme an das Haus ab: Temperaturabfall des Speicherfühlers mal Inhalt
  (`volumen_l`). Jede solche Entladung erhält die Heizgradtage ihres Zeitraums, anteilig aus dem
  Tagesprotokoll; Ladungen, zwischen denen weniger als sechs Stunden liegen, etwa ein
  nachzündender Kessel, gelten als eine. Eine nach Dauer gewichtete Gerade ergibt Wärme je
  Heizgradtag und den Sockel bei null Heizgradtagen, also Warmwasser samt Verlusten von Speicher
  und Leitungen. Nötig sind mindestens 8 Entladungen über 10 Tage und 3 Heizgradtage Spreizung;
  Tage mit unvollständiger Außentemperatur und Lücken über vier Tage gehen nicht ein. Dazu die
  Ladeleistung: Wärme in den Speicher je Brennerstunde aus den Ladungen mit mindestens 20 Minuten
  Brenner, und der Düsendurchsatz, der mit dem angenommenen Wirkungsgrad dazu passt.
- **Tankablesungen:** Zwei Ablesungen des Tankinhalts im Abstand einiger Wochen, samt nachgetankter
  Liter, ergeben mit den aufgezeichneten Brennerstunden den tatsächlichen Düsendurchsatz. Er
  ersetzt die Annahme, sobald mindestens 20 Brennerstunden und 90 % der Zeit dazwischen
  aufgezeichnet sind.
- **Vorlauftemperatur je Heizkreis:** die Heizkurve der letzten 90 Tage, verlängert bis zur
  Normaußentemperatur, und der höchste Vorlauf in der kältesten Zeit. Bewertet wird der Wert erst,
  wenn die Heizkurve mindestens die Hälfte der Unterschiede erklärt und die Messungen bis 15 K an
  die Normaußentemperatur heranreichen; Richtwerte bis 35 °C sehr günstig, bis 45 °C günstig, bis
  55 °C möglich.
- **Räume bei Kälte:** im kältesten Viertel der Stunden die Räume, die bei mindestens 90 % offenen
  Ventilen mehr als 0,5 K unter dem Sollwert blieben, danach die mit den am weitesten geöffneten
  Ventilen. Sie begrenzen, wie weit sich der Vorlauf senken lässt.

Die App nennt, was die Werte schwächt: angenommener Durchsatz, eine weit verlängerte Gerade, eine
Verbrauchslinie mit geringer Bestimmtheit oder einen Auslegungstag mit mehr als 24 Brennerstunden.

### Abgas-Vorlauf-Abstand

Wie weit die höchste Abgastemperatur einer Ladung über dem höchsten Kesselvorlauf liegt, sagt,
wie viel Wärme durch den Schornstein geht statt ins Wasser. Bei sauberem Kessel ist der Abstand
klein und stabil; Ruß im Wärmetauscher hebt ihn über Wochen an. Grob zwanzig Kelvin entsprechen
einem Prozentpunkt Wirkungsgrad.

Verglichen wird der Median der jüngsten fünfzig Ladungen mit dem Median der ersten fünfzig nach
der letzten Reinigung. Der Median, nicht der Mittelwert: Eine einzelne Ladung mit hohem
Abgaswert — etwa ein Start in den kalten Kessel — soll das Bild nicht verschieben.

Nach einer Reinigung drücken Sie **Kessel gereinigt — ab jetzt neu messen**. Damit bilden die
folgenden Ladungen den sauberen Zustand ab. Ohne dieses Datum steht der laufende Median da, aber
kein Vergleich; Ladungen aus der Zeit davor bilden den Bezug nicht, sonst sähe der saubere Kessel
besser aus, als er ist.

Der Zeitpunkt der nächsten Reinigung wird damit eine Messung statt eines Kalendereintrags.

### Warmwasser

Im Sommer verbraucht die Anlage täglich Öl, ohne dass ein Raum Wärme abruft. Darin stecken zwei
Dinge: das Warmwasser und der Stillstandsverlust des Speichers. Sie sehen im Verlauf verschieden
aus — der Verlust ist ein langsames, stetiges Absinken, eine Zapfung ein steiler Einbruch. An
dieser Anlage gemessen: **0,8 K je Stunde** im Stillstand gegen **6,5 K in einer halben Stunde**
für ein Vollbad.

Die Karte **Pufferspeicher** weist deshalb aus, wie oft am Tag gezapft wurde und wie viel dabei
entnommen wurde. Gezählt wird in Kelvin; ist der Speicherinhalt eingetragen, steht die Angabe
zusätzlich in Kilowattstunden. Während einer Ladung wird nicht gezählt — dort steigt der Speicher,
und was gleichzeitig gezapft wird, lässt sich am Fühler nicht abtrennen.

### Befunde

Auffälligkeiten stehen gesammelt auf der Anlagenseite, nicht über die Karten verstreut. Die
Schnittstelle führt sie unter `findings` in `GET /api/state`, jeweils mit einer festen Kennung
(`code`), dem Ort (`where`) und einem Text:

| Befund | Kennung | Bedingung und Bedeutung |
|---|---|---|
| Vorlauf und Rücklauf vertauscht | `flow_swapped` | Bei laufender Pumpe und einem Speicher ab 35 °C ist der Vorlauf eines Kreises länger als eine halbe Stunde mehr als 1 K kälter als sein Rücklauf. Gezählt wird erst, wenn die Pumpe fünf Minuten läuft, und nur, solange das Relais sie als eingeschaltet meldet. Entweder sitzen die Fühler an den falschen Rohren, oder ihre Rollen sind vertauscht zugeordnet. |
| Fühler verwirft viele Messungen | `probe_errors` | Mehr als 5 Prozent der Messungen eines Fühlers seit dem Start sind verworfen worden, gezählt ab hundert Messungen. Meist ein Wackelkontakt, eine zu lange Leitung oder ein zu schwacher Anschlusswiderstand. |
| Warmes Wasser strömt in den Kesselrücklauf | `backflow` | Bei stehender Pumpe und ausgeschaltetem Brenner steigt der Kesselrücklauf um mindestens 3 K über seinen Tiefstwert. Von selbst kann er dabei nicht wärmer werden. An dieser Anlage sprang er bei einer Warmwasserzapfung von 36,9 auf 46,3 °C, während der Vorlauf bei 32 °C blieb: Heißes Wasser wird in die Rücklaufleitung gedrückt und kühlt dort ab. Meist fehlt eine Schwerkraftbremse oder sie ist undicht; jede Zapfung führt dann Wärme in den kalten Kessel. |
| Tag über der Verbrauchslinie | `day_above_trend` | Die Brennerlaufzeit des letzten abgeschlossenen Tages liegt mehr als drei Standardabweichungen über der Verbrauchslinie, siehe oben. |
| Kessel überträgt schlechter | `flue_gap_rising` | Der Abgas-Vorlauf-Abstand der letzten Ladungen liegt mehr als 15 K über dem Stand nach der Reinigung, siehe oben. |

Die Prüfung auf vertauschte Fühler urteilt nur, solange sich der Zustand beurteilen lässt; steht
die Pumpe, ruht sie, statt von vorn zu beginnen. Die Standzeit zählt dabei nicht zur Haltezeit,
ebenso wenig die ersten fünf Minuten nach dem Anlaufen: In dieser Zeit steht noch das Wasser der
Standzeit in den Rohren, und der Rücklauf ist oft wärmer als der Vorlauf. Gemeldet wird erst, wenn
der Zustand eine halbe Stunde beurteilbar anliegt, und nur, solange die Pumpe läuft. Steht sie,
verschwindet die Meldung und kehrt nach der nächsten Einlaufzeit zurück, falls der Zustand weiter
zutrifft. Sie erlischt, sobald er beurteilbar nicht mehr zutrifft. Die Rückströmung zählt Ereignisse: Der Befund bleibt stehen,
bis das Gerät neu startet, und nennt ihre Anzahl sowie den größten Anstieg. Verbrauchslinie und
Abgasabstand werden aus den Protokollen berechnet und ändern sich nur mit einem neuen Tag bzw.
einer neuen Ladung.

## Schutzfahrt und Schutzlauf

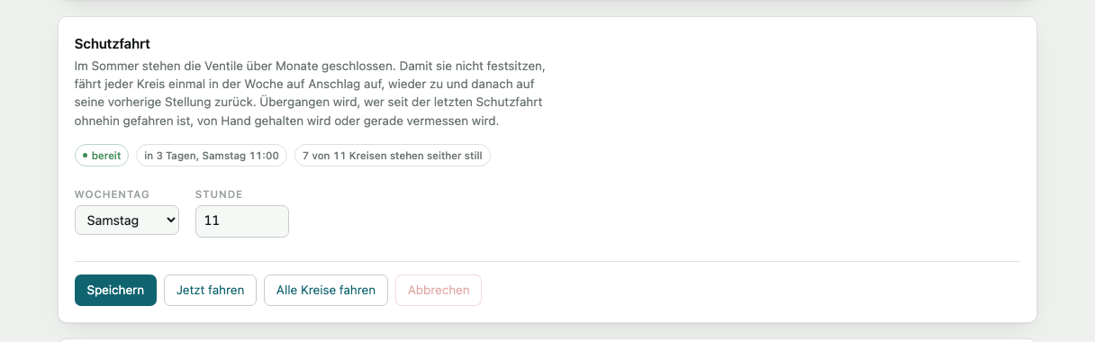
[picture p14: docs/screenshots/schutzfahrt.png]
Schutzfahrt


Im Sommer stehen die Ventile über Monate geschlossen und die Umwälzpumpen still. Beides setzt
sich mit der Zeit fest. Einmal in der Woche fahren deshalb alle Ventile einmal durch und alle
Pumpen laufen kurz an.

Der Termin steht auf beiden Gerätearten unter **System** und ist ab Werk **Samstag 11 Uhr** —
eine Stunde nach dem täglichen Neustart der Verteilerplatinen, damit sich beides nicht in die
Quere kommt. Wochentag auf „kein Termin" schaltet ihn ab.

**An der Verteilerplatine.** Jeder Kreis fährt einmal auf, auf Anschlag wieder zu und danach auf
seine vorherige Stellung zurück. Zu wird auf Anschlag gefahren, nicht auf eine Stellung: Das
Ventil schließt ganz, und die Stellung ist danach wieder gesichert statt geschätzt. Auf endet die
Fahrt wie jede gewöhnliche Fahrt bei 92 % des Hubs (siehe
[Abstand zum Anschlag auf](#abstand-zum-anschlag-auf)). Die Kreise fahren nacheinander, je
Messgruppe einer; für alle elf dauert das rund zwanzig Minuten.

| Übergangen wird | Grund |
|---|---|
| Kreise, die seit der letzten Schutzfahrt gefahren sind | wer regelt, sitzt nicht fest — und die Fahrt käme dem Raum in die Quere |
| Kreise in Notstellung von Hand | die Handbedienung hat Vorrang |
| Kreise, die gerade vermessen werden | die Messfahrt darf nicht gestört werden |

**Jetzt fahren** stößt die Schutzfahrt außerhalb des Termins an, **Alle Kreise fahren** nimmt
auch die zwischenzeitlich gefahrenen mit. **Abbrechen** streicht die noch offenen Kreise;
angefangene Fahrten laufen zu Ende, weil ein Ventil auf halbem Weg schlechter stünde als eines,
das seine Fahrt abschließt.

**Am Heizungsgerät.** Jede Heizkreispumpe läuft drei Minuten. Übergangen wird eine Pumpe, die in
den letzten 24 Stunden ohnehin gelaufen ist. Die Kesselkreispumpe hat keinen Schutzlauf; sie läuft
bei jeder Ladung. Der Schutzlauf gilt unabhängig von Bedarf und Speichertemperatur — er dient
dem Lager, nicht der Wärme.

Gemessen wird der Termin an der Uhr, nicht an der Laufzeit seit dem Einschalten. Das ist der
Unterschied, auf den es ankommt: Die Verteilerplatinen starten täglich um 10 Uhr neu und
erreichen nie sieben Tage Laufzeit; ein Termin, der daran hinge, käme nie. Steht die Uhr noch
nicht, fällt der Termin aus, statt im Jahr 1970 zu liegen. Wer zur Terminstunde aus war und
später am selben Tag angeht, holt ihn nach.

## Verlauf und Aufzeichnung

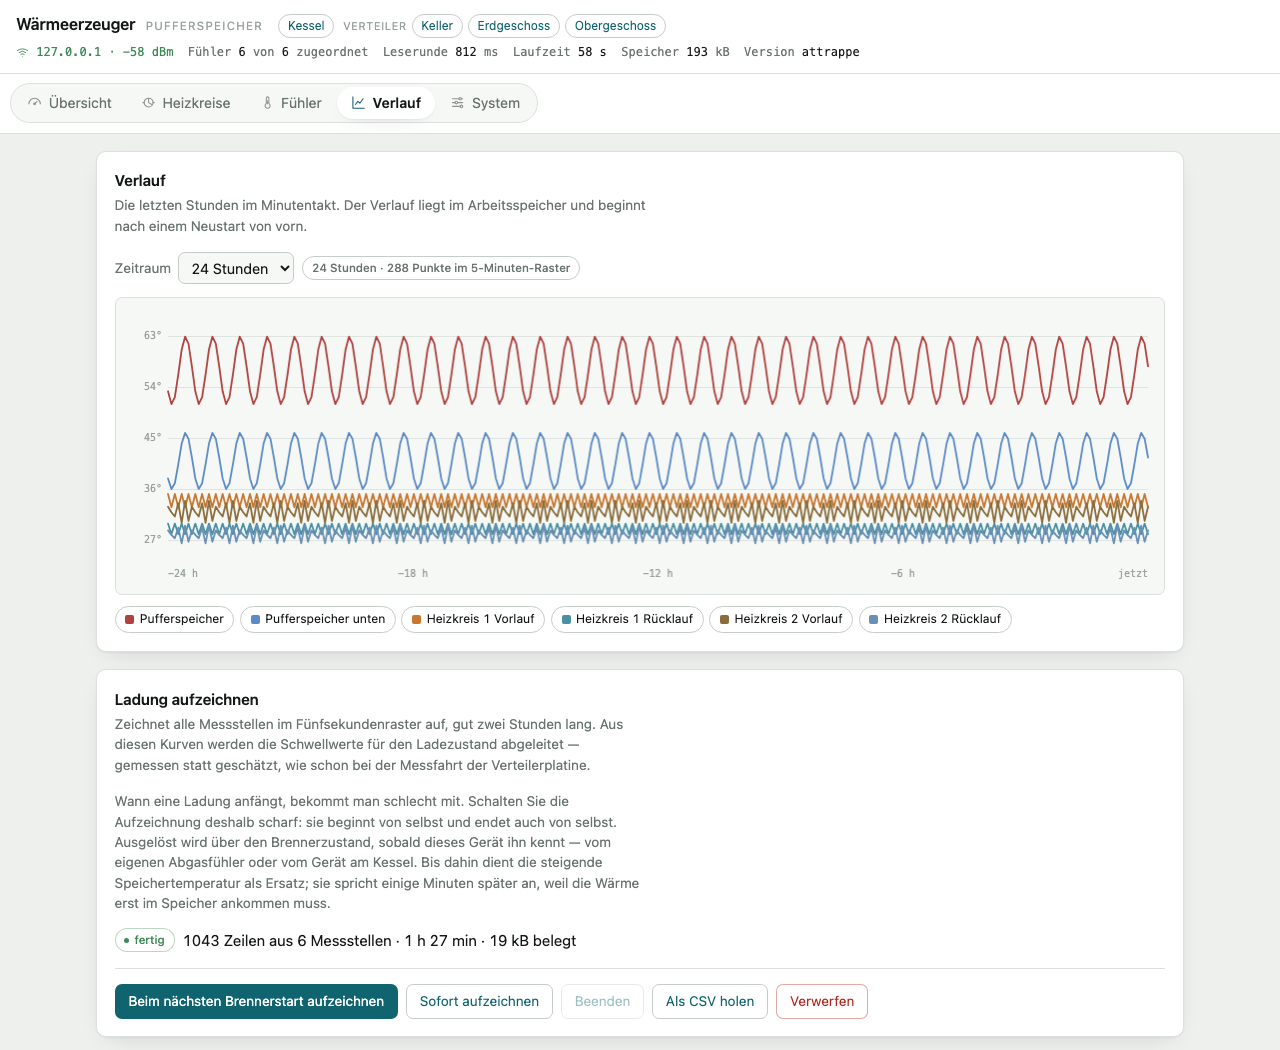
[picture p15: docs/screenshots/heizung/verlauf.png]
Verlauf


**Verlauf.** Die letzten 24 Stunden im Minutentakt. Die Messreihen lassen sich einzeln
zuschalten. Der Verlauf liegt im Arbeitsspeicher und beginnt nach einem Neustart von vorn. Er führt alle
Messstellen, die das Gerät je gesehen hat — auch die vom Nachbargerät. Fällt eine davon
vorübergehend aus, bleibt ihre Spalte bestehen und der Verlauf läuft weiter.

**Ladung aufzeichnen.** Zeichnet alle belegten Messstellen im Fünfsekundenraster auf, gut zwei
Stunden lang.

Wann eine Ladung anfängt, bekommt man schlecht mit. Schalten Sie die Aufzeichnung deshalb scharf:

1. **Beim nächsten Brennerstart aufzeichnen**
2. Die Aufzeichnung beginnt von selbst und endet auch von selbst
3. **Als CSV holen** lädt die Datei herunter
4. **Verwerfen** gibt den Arbeitsspeicher wieder frei

Ausgelöst wird über eines von zwei Zeichen. Welches, sagt die Zustandszeile.

| Zeichen | Voraussetzung | Beginn | Ende |
|---|---|---|---|
| **Brennerzustand** | eigener Abgasfühler, oder ein Gerät am Kessel meldet ihn | der Brenner läuft an | zehn Minuten nach dem Brennerlauf |
| **Speichertemperatur** | ein Fühler mit der Rolle `puffer` | sie steigt um 1,5 K in zwanzig Minuten | eine Viertelstunde ohne neuen Höchstwert |

Der Brennerzustand hat Vorrang: er ist das unmittelbare Zeichen. Die Speichertemperatur ist der
Ersatz für ein Gerät am Pufferspeicher, solange das Gerät am Kessel noch nicht steht — sie
spricht einige Minuten später an, weil die Wärme erst im Speicher ankommen muss. Kennt ein Gerät
weder das eine noch das andere, lässt es sich nicht scharf schalten und sagt das mit Begründung.

Über den Brennerzustand gilt außerdem: Schaltet der Kessel zwischendurch ab und gleich wieder
ein, läuft die Aufzeichnung durch — taktender Betrieb gehört zur selben Ladung. Läuft der Brenner
in dem Augenblick, in dem Sie scharf schalten, wird der übernächste Start abgewartet; eine halbe
Kurve taugt zur Auswertung nicht. **Abbrechen** hebt die Schaltung auf.

Der Arbeitsspeicher wird schon beim Scharfschalten belegt, damit ein Fehlschlag sofort auffällt
und nicht erst dann, wenn der Kessel nachts anspringt.

Die Schaltung übersteht einen Neustart: Sie wartet womöglich stundenlang auf die nächste Ladung,
und ein Neustart dazwischen darf das nicht verwerfen. Der Inhalt einer bereits **laufenden**
Aufzeichnung liegt dagegen im Arbeitsspeicher und ist danach weg — das Gerät ist dann wieder
scharf und wartet auf die nächste Ladung.

**Sofort aufzeichnen** beginnt ohne Umweg — für den Fall, dass der Kessel gerade läuft und Sie
den Rest der Kurve haben wollen. Eine so begonnene Aufzeichnung endet nicht von selbst, sondern
erst über **Beenden** oder wenn der Speicher voll ist.

Aufgezeichnet werden nur die Messstellen, die beim Start belegt sind; sind Kesselwerte über das
Nachbargerät erreichbar, kommen sie mit hinein. Die Datei zeigt damit die ganze Anlage, nicht nur
die Hälfte, die an einem Gerät hängt.

Aus diesen Kurven werden die Schwellwerte für den Ladezustand abgeleitet — gemessen statt
geschätzt, wie schon bei der Messfahrt der Verteilerplatine.

## Leitstand

Der Leitstand ist ein zusätzliches Gerät, ein M5Stack Core mit eigener Firmware
(`apps/station`). Er regelt nichts und schaltet nichts. Er zeigt den Zustand der Anlage auf
seinem Bildschirm, empfängt Funkthermometer, liefert die Außentemperatur an die Heizungsgeräte und
zeichnet alle Geräte auf seiner SD-Karte auf. HomeKit und der Abgleich des Verlaufs mit der App
folgen in späteren Etappen; Plan und Begründung stehen im [Konzept Leitstand](konzept-leitstand.md).

### Einrichten

1. Firmware aufspielen. Beim ersten Mal über USB, im Verzeichnis `apps/station` mit
   `idf.py -p <Port> flash`; danach über `POST /api/ota` wie bei den anderen Geräten. Das Öffnen
   der seriellen Schnittstelle startet das Gerät neu; geprüft wird deshalb über das Netz.
2. Ohne WLAN-Zugang öffnet der Leitstand einen Zugangspunkt `leitstand-XXXX`, ab Werk ohne
   Kennwort. Der Bildschirm nennt Netz und Adresse. Eingerichtet wird entweder in der App unter
   **Einrichtung › Neues Gerät** mit der Auswahl **Leitstand** oder im Browser: verbinden,
   `http://192.168.4.1` öffnen und unter **Einstellungen** das Heimnetz wählen. Die App schreibt
   Ort und WLAN-Zugang und nimmt den Leitstand danach selbst auf; den Gerätenamen `leitstand`
   ändert sie nicht, weil die Regelgeräte ihn unter diesem Namen suchen.
3. Im Heimnetz meldet er sich per mDNS mit der Rolle `station` und einer Kennung `lst_…` an. Er
   findet die Verteilerplatinen und Heizungsgeräte selbst; einzutragen ist nichts.

In der App erscheint er in der Einrichtung mit einem eigenen Symbol und wird dort aufgenommen.
Die App führt ihn unter **Geräte → Leitstand**, getrennt von den Regelgeräten: Er hat keine
Parameter, keine Sicherung und gehört zu keiner Etage.

### Bildschirm und Tasten

Am Core2 gibt es sechs Seiten, am Core Basic nur Anlage und Leitstand: Verlauf und Ereignisse
brauchen Speicher, den der Core Basic nicht hat.

| Seite | Inhalt | Mittlere Taste |
|---|---|---|
| Anlage | Kessel mit Vorlauf, Rücklauf und Abgas, Brenner an oder aus mit Laufzeit und Starts des Tages, Speicher mit Füllstand, Außentemperatur | – |
| Räume (Core2) | alle Räume aller Verteiler mit Ist, Soll, Ventilstellung und Feuchte, nach Etage; ein Raum unter seinem Sollwert steht in Blau, ein ausgeschalteter mit „aus“ | nächste Seite der Liste |
| Verlauf (Core2) | 24 Stunden: Speicher, Kesselvorlauf (gestrichelt), Außen, darunter der Brennerlauf als Balken | Raumwerte: die Temperatur jedes Raums |
| Meldungen (Core2) | offene Befunde der Heizungsgeräte, darunter die Ereignisse des Tages mit Uhrzeit, neueste zuerst | ältere Ereignisse |
| Geräte (Core2) | je Gerät Erreichbarkeit, WLAN, Laufzeit seit dem Neustart (unter einem Tag hervorgehoben), freier Speicher, Fassung; darunter der Außenfühler mit Schlüsselzustand | Funkthermometer in Reichweite |
| Leitstand | Uhrzeit, WLAN, freier Speicher, erreichbare Geräte, Außenfühler, Protokoll, HomeKit, Firmware, Gerät mit Versorgung (Core2: Netz oder Akku mit Ladestand) | HomeKit-Code mit QR-Code |

- **Linke und rechte Taste** blättern zwischen den Seiten. Der erste Druck auf einen dunklen
  Bildschirm weckt ihn nur.
- **Mittlere Taste**, anderthalb Sekunden gehalten, schaltet den Bildschirm aus und wieder an;
  kurz gedrückt schaltet sie innerhalb der Seite um (Tabelle). Was sie tut, steht in der Mitte
  des Fußes.
- **Berührung (Core2):** Die drei Tasten sind die Felder unter dem Bildschirm. Auf dem Bildschirm
  blättert Wischen nach links oder rechts zur nächsten oder vorigen Seite; Wischen nach oben oder
  unten wirkt wie die mittlere Taste; Tippen auf den Fuß wie die Taste darunter.
- Kommt ein neuer Befund hinzu, schaltet sich die Anzeige am Core2 ein und zeigt die Seite
  Meldungen.
- Nach `dim_after_min` Minuten ohne Bedienung wird er auf ein Sechstel der Helligkeit
  abgedunkelt, in der Nacht zwischen `night_from_h` und `night_to_h` nach einer Minute ganz
  ausgeschaltet.

Den Verlauf hält der Leitstand im PSRAM; nach einem Neustart liest er die letzten 24 Stunden aus
den Fünfminutendateien der Karte. Die Seite lässt sich auch aus der App umschalten, und die App zeigt ein Abbild des Bildschirms
(`GET /api/screen`). Das Bild wird zeilenweise gelesen; währenddessen steht der Bildschirm für
einen Augenblick still.

### Funkthermometer und Außenfühler

Der Leitstand empfängt dieselben Thermometer wie die Verteilerplatinen: BTHome offen und
verschlüsselt, etwa den Climate-Sat von camperSense, dazu RuuviTag sowie Xiaomi- und
ATC-Thermometer. Der
Schlüssel eines verschlüsselten Thermometers, 32 Hexadezimalziffern aus der Hersteller-App, wird
unter **Funk** oder in der App unter **Leitstand → Funkthermometer** hinterlegt. Dort steht auch,
ob er passt.

Eines der Thermometer wird dort **als Außenfühler** zugeordnet. `GET /api/demand` liefert seinen
Wert als `outdoor_c` mit dem Alter `outdoor_age_s`, solange er nicht älter als eine Viertelstunde
ist. Heizungsgeräte ab der Fassung nach 0.4.0 fragen den Leitstand zuerst und weichen erst dann
auf eine Verteilerplatine aus (siehe [Außenfühler](#außenfühler)). Der Leitstand selbst meldet
keinen Wärmebedarf.

Empfängt der Leitstand den Außenfühler nicht selbst oder ist dessen Wert älter als eine
Viertelstunde, übernimmt er den jüngsten Wert einer Verteilerplatine, die einen Außenfühler
empfängt. Anzeige, HomeKit und `GET /api/demand` zeigen dann diesen Wert; die Seite Anlage nennt
statt „Funk“ die Platine, von der er stammt, und `GET /api/state` führt sie unter
`outdoor.source`. Der eigene Empfang geht vor, sobald er wieder frisch ist.

Raumthermostate in HomeKit folgen den Räumen der Verteiler: Führt ein erreichbarer Verteiler einen
Raum nicht mehr, entfernt der Leitstand das zugehörige Zubehör. Ein Verteiler, der nicht antwortet,
behält seine Räume; sie zeigen in Home „Keine Antwort“.

### Protokoll auf der SD-Karte

Der Leitstand fragt jedes Gerät alle 30 Sekunden ab und schreibt, was es liefert, auf die Karte.
Je Tag, gezählt in UTC, entsteht ein Verzeichnis `protokoll/<jahr>/<tag>/`:

| Datei | Inhalt |
|---|---|
| `geraete.json` | Kennung, Ort, Art und Firmware je Gerät |
| `<kennung>.csv` | Messwerte im Takt der Abfrage |
| `<kennung>.5min.csv` | Mittelwerte je fünf Minuten, im Raster der App |
| `ereignisse.jsonl` | Neustart mit Grund, Erreichbarkeit, Firmware, Brenner und Pumpen mit Dauer, Sollwerte, Betriebsarten, Befunde |
| `zustaende.jsonl` | vollständiger Zustand jedes Geräts alle 15 Minuten und bei neuer Firmware |
| `protokolle/<kennung>.ladungen.csv`, `.tage.csv` | Ladungs- und Tagesprotokoll der Heizungsgeräte, einmal am Tag vollständig übernommen |

Welche Spalten eine Datei hat und was sie bedeuten, steht im
[Katalog der Messgrößen](katalog-messgroessen.md). Kommt im Laufe des Tages eine Spalte hinzu,
etwa durch einen neuen Raum, beginnt eine neue Datei `<kennung>.2.csv`.

- **Karte:** FAT32. Vorgesehen ist eine Ausführung für Dauerbetrieb mit 16 GB; der Leitstand
  schreibt rund 4 MB am Tag. Ohne Karte läuft er weiter und versucht es jede Minute erneut. Wird
  die Karte im Betrieb gezogen oder getauscht, merkt er das binnen zehn Sekunden an ihrem Status,
  gibt die Einbindung auf und bindet die neue ein; beides steht als Ereignis `leitstand` im
  Protokoll. Sicherer bleibt es, ihn für den Tausch vom Strom zu nehmen. Eine Karte mit anderem
  Dateisystem oder mehreren Partitionen, etwa von einem Raspberry Pi, formatiert der Leitstand unter
  **Protokoll → Karte formatieren** als eine FAT32-Partition über die ganze Karte; alles darauf
  geht dabei verloren. Eine Karte mit 64 GB braucht dafür rund 15 Sekunden.
- **Schreiben:** Jede Zeile geht sofort auf die Karte: Datei öffnen, anhängen, schließen. Ein
  Stromausfall kostet höchstens die Zeile, die gerade geschrieben wird. Das Konzept sah vor, eine
  Minute im Arbeitsspeicher zu sammeln; dafür ist auf dem Core ohne PSRAM kein Platz.
- **Uhrzeit:** Ohne gestellte Uhr wird nichts geschrieben. Wie viele Abfragen bis dahin
  verworfen wurden, steht im Ereignis `leitstand` beim Start.
- **Platz:** Unterschreitet der freie Platz 10 Prozent, löscht der Leitstand stündlich die
  ältesten Zustände und Messwerte im Takt der Abfrage. Fünfminutenmittel und Ereignisse bleiben.
- **Abruf:** Die Weboberfläche zeigt unter **Protokoll** den Stand der Karte und die Tage mit
  ihren Dateien zum Herunterladen. `GET /log/<tag>/<datei>` liefert eine Datei, mit
  `Range: bytes=N-` ab Stelle N; alle Dateien wachsen nur.
- **Auswertung am Gerät:** `GET /api/log/series` liefert ausgewählte Messgrößen eines Geräts in
  wählbarem Raster, `GET /api/log/events` die Ereignisse eines Zeitraums, beides als JSON.
- **Prüfen:** `python3 tools/protokoll_pruefen.py leitstand.local [tag]` holt die Dateien eines
  Tages und prüft Spaltenzahl, Zeitfolge und JSON-Zeilen, zählt die Abtastungen je Gerät und
  meldet Lücken über vier Takte, die kein Ereignis belegt.

Der Bildschirm nennt auf der Seite Leitstand unter **Protokoll** den freien Platz, die seit dem
Start geschriebene Menge und Schreibfehler.

**In der App.** Die App übernimmt die Fünfminutenmittel des Leitstands in ihren Verlauf, beim
Verbinden und danach alle fünf Minuten. Vom laufenden Tag holt sie mit `Range` nur die Zeilen, die
seit dem letzten Abgleich hinzukamen; eine Zeile ohne Zeilenende bleibt für den nächsten Abgleich
stehen. Ein Tag gilt zehn Minuten nach Mitternacht (UTC) als abgeschlossen und wird danach nicht
mehr abgefragt. Die Werte des Leitstands haben Vorrang vor der eigenen Aufzeichnung der App, weil
sie den ganzen Zeitraum abdecken; ein zweiter Abgleich desselben Tages überschreibt, statt doppelt
zu zählen. Wie weit der Abgleich ist, steht je Leitstand in `Abgleich-<kennung>.json` neben dem
Verlauf und wird nach jeder Datei gesichert, sodass ein abgebrochener Abgleich an derselben Stelle
fortsetzt. Den Stand zeigt **Geräte › Leitstand › Verlauf**.

Heizung › Verlauf zeigt jede Gruppe in einem eigenen Diagramm mit eigener Skala; die Heizkreise
teilen eine Skala und zeigen die Außentemperatur auf einer festen rechten Achse (−10 bis 20 °C).
Über die Karte eines Heizkreises führt **Verlauf und Heizkurve** zum Vorlauf über der
Außentemperatur mit Ausgleichsgerade: Ihre Steigung ist die Heizkurve, wie sie sich einstellt.

Der Assistent liest die Ereignisse über das Werkzeug `ereignisse`, etwa für „Wie oft ist der
Brenner gestern angesprungen?“. Mit `feinverlauf` holt er Messwerte im Takt der Abfrage vom
Leitstand, bis 24 Stunden, auch freien Speicher und WLAN-Empfang eines Geräts; das geht nur im
Heimnetz. `verlauf` reicht bis ein Jahr, über 30 Tage in Tagesmitteln.

**Analysepaket.** Unter **Einstellungen › Daten › Analysepaket erstellen** entsteht ein ZIP mit
dem Verlauf eines Zeitraums (7 Tage bis 1 Jahr) im gewählten Raster (5 Minuten bis 1 Tag): je
Gerät eine CSV-Datei mit den Spalten des Katalogs, Zeiten in UTC, dazu `ereignisse.csv`,
`anlage.json` mit Geräten, Räumen und Heizkreisen, der Katalog der Messgrößen und `LIESMICH.txt`.
Es enthält Gerätekennungen, Orts- und Raumnamen, aber keine Adressen und keine Zugangsdaten. Die
App gibt es nur über **Teilen** weiter.

Ebenso übernimmt die App `ereignisse.jsonl`. **Heizung › Verlauf** markiert im Diagramm Neustarts
(rot nach Absturz, Wächter oder Unterspannung), neue Firmware und neue Befunde der gezeigten Geräte
und legt einen grauen Streifen über die Zeit, in der ein Gerät nicht erreichbar war; darunter stehen
dieselben Ereignisse als Liste mit Grund und Dauer. Der Verlauf eines Raums markiert, wann er ein-
oder ausgeschaltet wurde, und Neustarts seines Verteilers. Ist eine Datei auf dem Leitstand kürzer
als das bereits Übernommene, wurde die Karte getauscht oder formatiert; die App liest den Tag dann
von vorn. Nach **Einstellungen › Verlauf löschen** übernimmt sie alles, was auf der Karte liegt,
erneut.

### HomeKit

Auf dem Core2 (mit PSRAM) ist der Leitstand eine HomeKit-Brücke. Am Core Basic bleibt HomeKit
aus; die Seite Leitstand sagt dann „aus · braucht PSRAM“.

- **Je Raum ein Thermostat:** Isttemperatur, Sollwert von 5 bis 35 °C in Schritten von 0,5 K,
  Betriebsart aus oder heizen, Heizzustand (Ventile offen) und Luftfeuchte, sofern das
  Raumthermometer sie liefert.
- **Fühler:** Außen (Temperatur und Feuchte), Pufferspeicher und Kesselvorlauf, sobald die
  Anlage sie liefert.
- **Schreiben:** Sollwert und Betriebsart gehen nach 900 ms Sammelzeit an den zuständigen
  Verteiler, über dieselben Endpunkte wie die App; das Verschieben eines Reglers in Home löst so
  nur einen Befehl aus. Scheitert er, versucht es der Leitstand dreimal im Abstand von zwei
  Sekunden. Bis die Abfrage den neuen Wert zeigt, höchstens eine Minute, behält Home den
  eingestellten Wert.
- **Nicht erreichbar:** Antwortet ein Verteiler nicht, zeigen seine Räume in Home „Keine Antwort“
  statt veralteter Werte.
- **Nicht über HomeKit:** Pumpen und Einstellungen der Anlage.
- **Hinzufügen:** Den Code erzeugt der Leitstand beim ersten Start und behält ihn. Er steht nur
  auf der Anzeige (Seite Leitstand, mittlere Taste kurz), als Zahl und als QR-Code; weder die App
  noch die Weboberfläche zeigen ihn. In der Home-App: Gerät hinzufügen, Code scannen.
- **Neue Räume** erscheinen in Home ohne neue Kopplung. Die Zuordnung eines Raums zu einem Zimmer
  in Home bleibt über Neustarts erhalten.
- **Kopplungen löschen:** in der App unter Geräte › Leitstand › HomeKit oder mit
  `POST /api/homekit/reset` und `{"bestaetigung":"KOPPLUNGEN LOESCHEN"}`. Der Code bleibt.
- Für Automationen und den Zugriff von unterwegs braucht Home eine Steuerzentrale (Apple TV oder
  HomePod).

**Echtzeituhr und Versorgung (Core2):** Nach einem Stromausfall stellt der Leitstand die Zeit aus
seiner Echtzeituhr, bevor das Netz sie liefert, und protokolliert ohne Lücke weiter; stündlich
stellt er die Uhr nach der Netzzeit nach. Fällt die Versorgung aus, läuft er auf dem Akku weiter
und schreibt ein Ereignis `leitstand` mit `versorgung_aus` samt Ladestand, bei Rückkehr
`versorgung_wieder`.

### Einstellungen

| Schlüssel | Vorgabe | Bedeutung |
|---|---|---|
| `site` | Leitstand | Name in der Kopfzeile und in der App |
| `outdoor.mac` | leer | Adresse des Außenfühlers; leer heißt keiner |
| `poll.heat_s` | 30 s | Abfragetakt der Heizungsgeräte |
| `poll.manifold_s` | 30 s | Abfragetakt der Verteilerplatinen |
| `display.brightness` | 160 | Helligkeit, 10 bis 255 |
| `display.dim_after_min` | 2 | Abdunkeln nach so vielen Minuten ohne Bedienung; 0 heißt nie |
| `display.night_from_h`, `display.night_to_h` | 23, 6 | Bildschirm nachts aus, zur vollen Stunde; −1 heißt nie |
| `wifi.ssid`, `wifi.pass`, `wifi.hostname`, `wifi.ap_pass`, `wifi.timezone` | —, —, `leitstand`, —, Mitteleuropa | wie bei den anderen Geräten |

Einen täglichen Neustart gibt es am Leitstand nicht. Die Heizungsgeräte werden alle 30 statt alle
10 Sekunden abgefragt, bis geklärt ist, ob ihre Neustarts am 23. September mit der häufigeren
Abfrage zusammenhingen.

### Schnittstelle

| Aufruf | Zweck |
|---|---|
| `GET /api/state` | Gerät, Netz, Speicher, Neustartgrund (`reset_reason`), Außenfühler, Funk, erreichbare Geräte, Anzeige, Protokoll (`log`) |
| `GET /api/plant` | zusammengefasster Zustand der abgefragten Geräte |
| `GET`/`PUT /api/config` | Einstellungen, ohne Kennwörter |
| `GET /api/ble`, `POST /api/ble/key` | empfangene Thermometer, Schlüssel setzen oder löschen |
| `GET /api/demand` | Außentemperatur für die Heizungsgeräte |
| `GET /api/peers` | gefundene Geräte |
| `GET /api/screen` | Abbild des Bildschirms als BMP |
| `POST /api/display` | Seite wählen, Bildschirm an oder aus |
| `POST /api/system/restart`, `/api/system/factory` | Neustart, Werksvorgabe |
| `POST /api/ota` | Firmware aktualisieren; während der Übertragung ruht die Abfrage der Anlage |
| `GET /api/log/days` | Tage mit Protokoll; mit `?tag=JJJJ-MM-TT` dessen Dateien samt Größe |
| `GET /log/<tag>/<datei>` | eine Datei des Protokolls, mit `Range: bytes=N-` ab Stelle N; die übernommenen Protokolle unter `protokolle/` |
| `GET /api/log/series?geraet=&schluessel=a,b&von=&bis=&raster=` | Mittel von bis zu acht Messgrößen je Raster; ab 300 s aus den Fünfminutenmitteln, höchstens 31 Tage, darunter aus den Rohwerten, höchstens 2 Tage; Zeiten in Sekunden seit 1970 |
| `GET /api/log/events?von=&bis=[&geraet=][&art=]` | Ereignisse eines Zeitraums, höchstens 31 Tage und 2000 Einträge |
| `POST /api/homekit/reset` | alle Kopplungen mit Home löschen; nur mit `{"bestaetigung":"KOPPLUNGEN LOESCHEN"}`. Den Stand (`active`, `reason`, `controllers`, `accessories`) liefert `GET /api/state` unter `homekit`, den Code nicht |
| `POST /api/log/lasttest`, `GET /api/log/lasttest` | Dauerlastprüfung: `{"mb":1024}` schreibt ein Muster auf die Karte, liest es zurück und vergleicht; der Betrieb läuft dabei weiter |
| `POST /api/log/format` | ganze Karte als FAT32 formatieren; nur mit `{"bestaetigung":"KARTE LOESCHEN"}` |
| `GET /api/coredump`, `POST /api/coredump/erase` | letzter Absturz: Task, Programmzähler, Ursache, Rücksprungadressen und Prüfsumme des ELF; löschen |

## Home Assistant

Es gibt zwei Wege; sie lassen sich einzeln oder gemeinsam nutzen.

### Über MQTT

Tragen Sie unter **System → MQTT** Broker, Benutzer, Kennwort und ein Themenpräfix ein. Die
Geräte melden ihre Entitäten selbst über MQTT-Discovery an. Welche entstehen, richtet sich
danach, was ein Gerät wirklich führt: ohne Abgasfühler keine Brenner-Entitäten, ohne Heizkreise
keine Pumpen.

### Über die Integration

Unter [`custom_components/floor_heating/`](../custom_components/floor_heating/) liegt eine
Integration für HACS. Sie spricht die Geräte unmittelbar über HTTP an und kommt ohne Broker aus.

1. Repository in HACS als eigene Quelle hinzufügen, Integration installieren, Home Assistant neu
   starten.
2. **Einstellungen → Geräte & Dienste → Integration hinzufügen → Fußbodenheizung**.
3. Adresse des Geräts eintragen.

Beide Gerätearten werden unterstützt; die Integration erkennt am Gerät selbst, welche vorliegt,
und richtet die passenden Entitäten ein.

| Verteilerplatine | Heizungsgerät |
|---|---|
| `climate` je Raum | Fühler als `sensor` |
| `cover` je Heizkreis | Brennerzustand, Laufzeit, Starts, Verbrauch |
| Raumthermometer als `sensor` | Füllstand und Ladezustand |
| Messfahrt und Notfahrt als Dienste | Pumpe und Bedarf je Kreis, Betriebsart als Auswahl |

## Wartung

### Firmware aktualisieren

**System → Firmware**, Datei wählen, **Einspielen**. Das Gerät startet neu. Läuft die neue
Fassung nicht an, kehrt der Bootlader zur vorherigen zurück; die Konfiguration bleibt in beiden
Fällen erhalten.

System
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

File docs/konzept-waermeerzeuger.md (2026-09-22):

# Konzept: Wärmeerzeugung, Pufferspeicher und Pumpensteuerung

Erweiterung des Projekts um zwei Geräte im Heizungsbereich. Der Umbau der Projektstruktur, der
dafür vorausgeht, ist in [umbau-projektstruktur.md](umbau-projektstruktur.md) beschrieben.

## Ausgangslage

Die drei Verteilerplatinen regeln die Ventilstellungen der Fußbodenheizung, wissen aber nichts
über die Wärmequelle. Umgekehrt laufen die beiden Heizkreispumpen am Pufferspeicher unabhängig
davon, ob überhaupt ein Ventil offen ist.
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

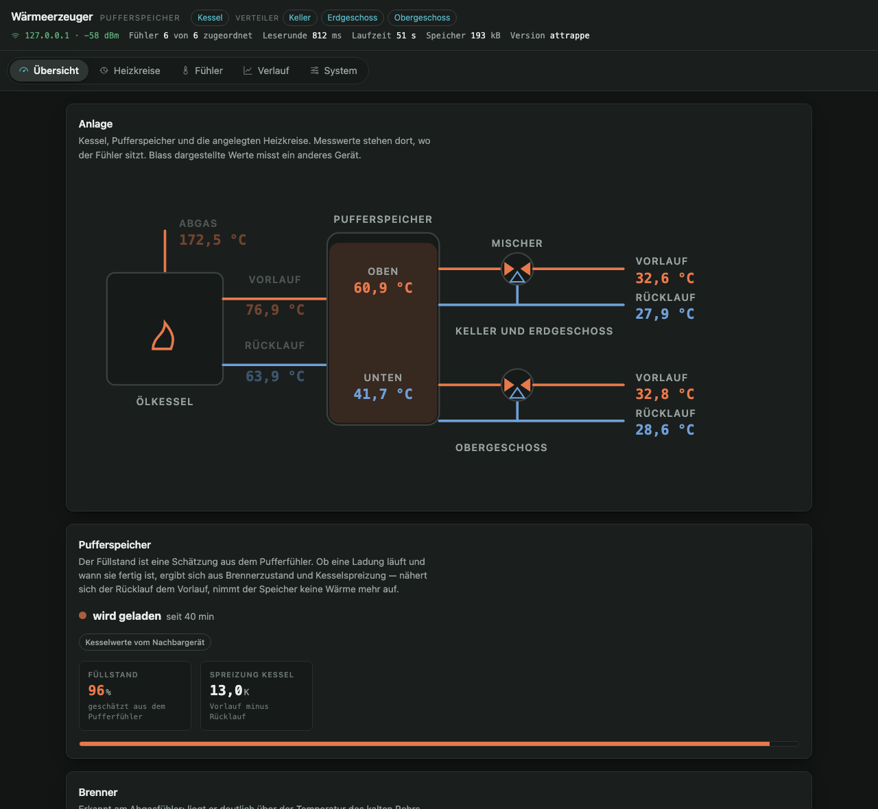
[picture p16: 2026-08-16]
docs/screenshots/heizung/uebersicht-dark.png

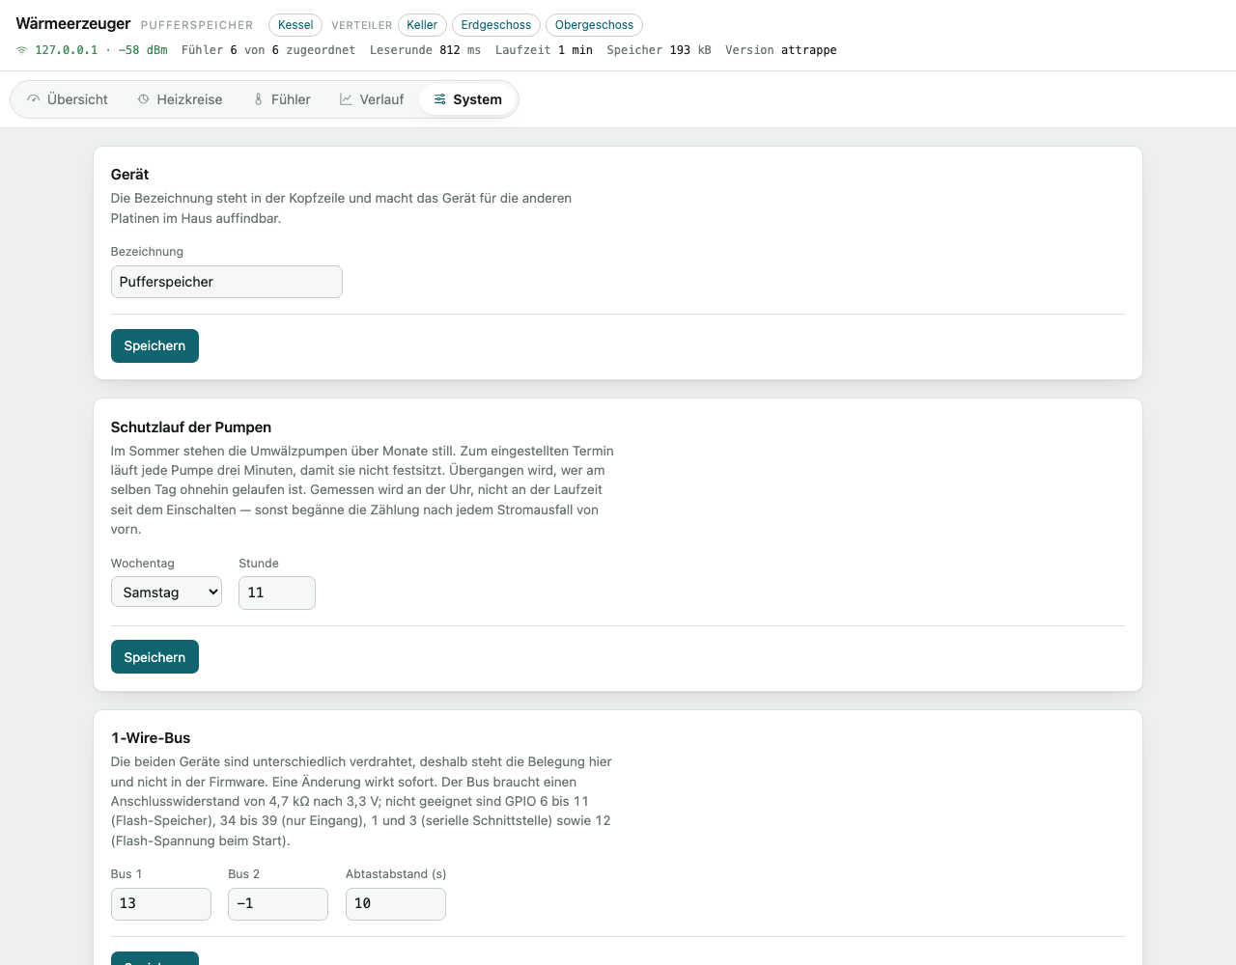
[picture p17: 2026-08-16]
docs/screenshots/heizung/system.png

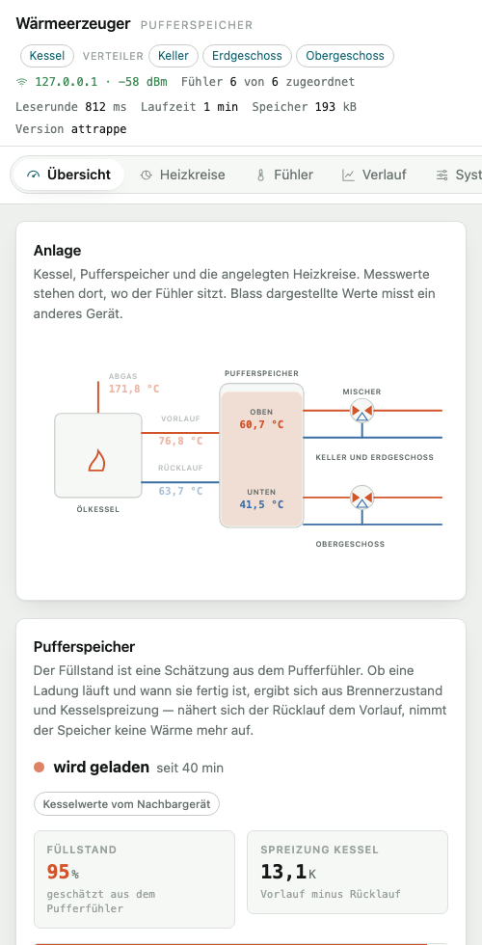
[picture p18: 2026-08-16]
docs/screenshots/heizung/mobil.png

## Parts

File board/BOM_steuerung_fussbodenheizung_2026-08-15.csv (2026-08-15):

ID | Name | Designator | Footprint | Quantity | Manufacturer Part | Manufacturer | Supplier | Supplier Part | Price
1 | 4.7K | R13 | R0402 | 1 | 0402WGF4701TCE | UniOhm | LCSC | C25900 | 0.005
2 | 10K | R12,R14 | R0402 | 2 | 0402WGF1002TCE | UniOhm | LCSC | C25744 | 0.008
3 | 100nF | C12 | C0603 | 1 | CC0603KRX7R9BB104 | YAGEO | LCSC | C14663 | 0.018
4 | HDC1080DMBR | HDC1080 | SENSOR-SMD_HDC1080DMBR | 1 | HDC1080DMBR | TI | LCSC | C82227 | 2.029
5 | KF250-3.5-3P-2 | 220 | CONN-TH_3P-P3.50_KF250-3.5-3P-2 | 1 | KF250-3.5-3P-2 | Cixi Kefa Elec | LCSC | C475164 | 0.177
6 | SN74HC595PWR | SN74HC595_1-4,SN74HC595_5-8,SN74HC595_9-12 | TSSOP-16_L5.0-W4.4-P0.65-LS6.4-BL | 3 | SN74HC595PWR | Texas Instruments | LCSC | C273642 | 0.164
7 | HLK-5M03 | U1 | PWRM-TH_HLK-5M03 | 1 | HLK-5M03 | HI-LINK | LCSC | C209906 | 3.019
8 | 1.0T-4P_C145956 | ONEWIRE,I2C-2,I2C-1 | CONN-SMD_1.0T-4P | 3 | - | Boom Precision Elec | LCSC | C145956 | 0.057
9 | 616-PCB-4P4C-90° | ONEWIRE_RJ11,RJ2,RJ3,RJ4,RJ5,RJ6,RJ7,RJ8,RJ9,RJ10,RJ11,RJ1 | RJ11-TH_616-PCB-4P4C-90 | 12 | - | Shenzhen Cankemeng | LCSC | C189737 | 0.17
10 | 100nF | C2,C3,C4,C5,C6,C7,C8,C9,C10,C11,C1 | C1206 | 11 | CL31B104KBCNNNC | SAMSUNG | LCSC | C24497 | 0.025
11 | HDR-F-2.54_1x2 | H2,H4,H5,H6,H7,H8,H9,H10,H11,H12,H1 | HDR-F-2.54_1X2 | 11 |  |  | LCSC | C49661 | 0.065
12 | 10K | R1-CH1,R1-CH2,R1-CH3,R1-CH4,R1-CH5,R1-CH6,R1-CH7,R1-CH8,R1-CH9,R1-CH10,R1-CH11,R2-CH1,R2-CH2,R2-CH3,R2-CH4,R2-CH5,R2-CH6,R2-CH7,R2-CH8,R2-CH9,R2-CH10,R2-CH11 | R1206 | 22 | 1206W4F1002T5E | UNI-ROYAL(Uniroyal Elec) | LCSC | C17902 | 0.018
13 | 12.4 | R2,R3,R4,R5,R6,R7,R8,R9,R10,R11,R1 | R1206 | 11 | 1206W4F124JT5E | Uniroyal Elec | LCSC | C407322 | 0.005
14 | L9110S | U6,U8,U9,U10,U11,U12,U13,U14,U15,U16,U7 | SOP-8_L5.0-W4.0-P1.27-LS6.0-BL | 11 | L9110S | UMW(Youtai Semiconductor Co., Ltd.) | LCSC | C725793 | 0.143
15 | ESP32D DEVKITC V4 COPY | U2 | ESP32D DEVKITC V4 | 1 | ESP32-DevKitC-32D | Espressif | Mouser | 356-ESP32-DEVKITC32D
16 | Screw_hole_M2.5 | H3,H13,H14,H15 | SCREW_HOLE_M2.5 | 4 | V6622F |  | Digi-Key | AE10791-ND

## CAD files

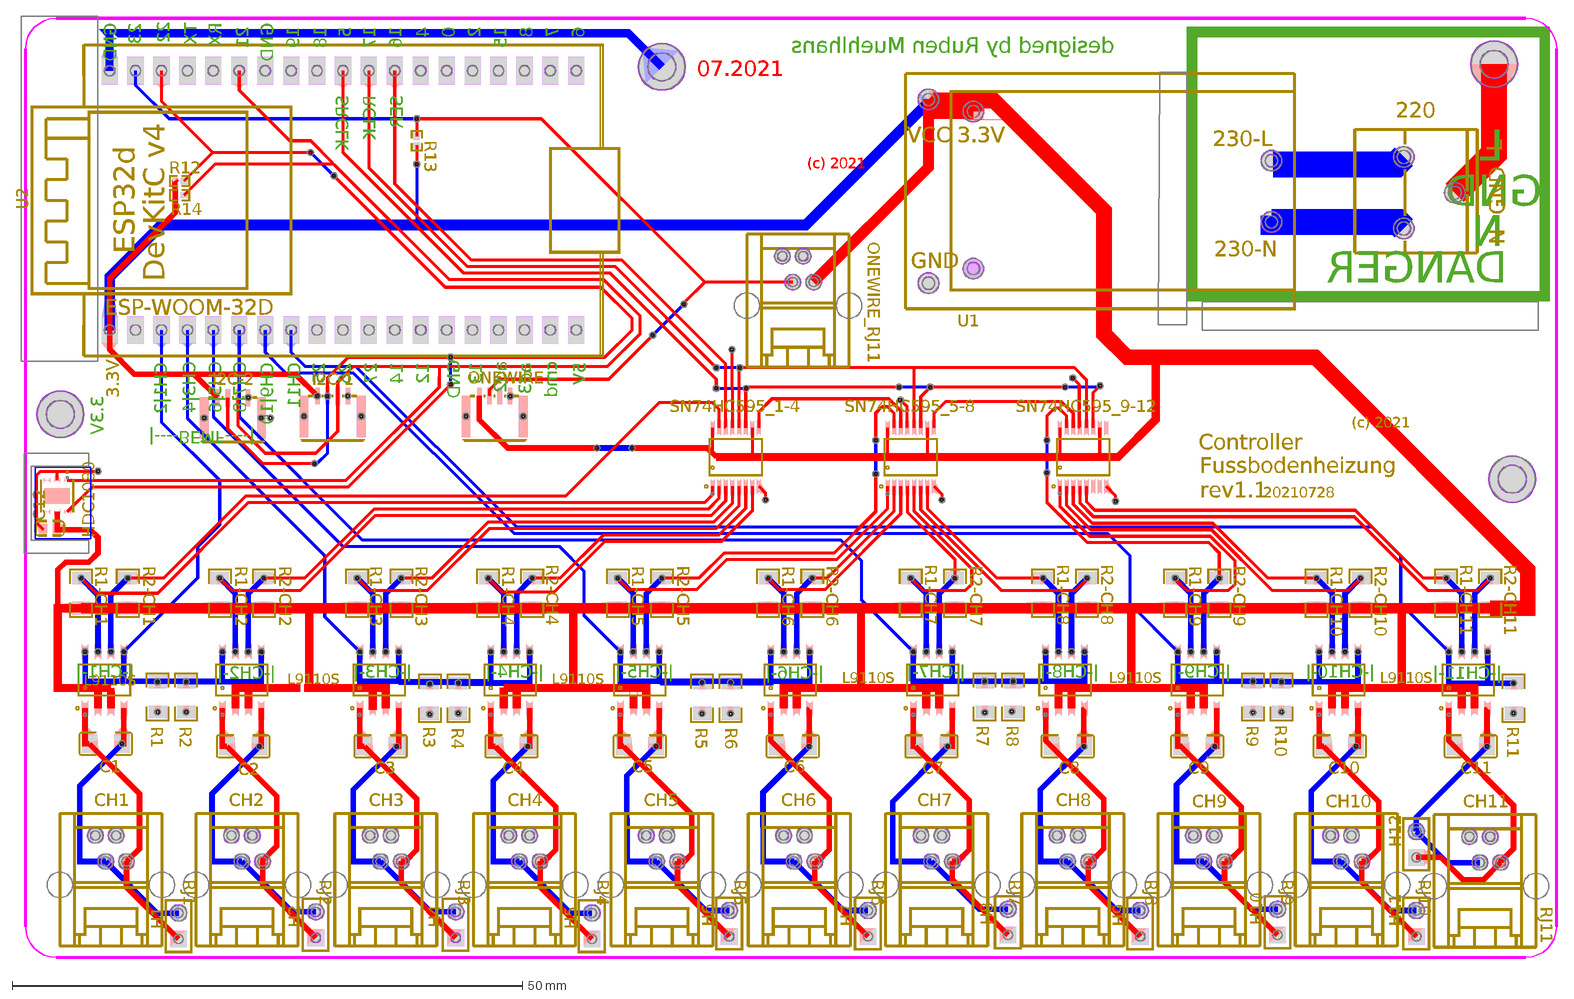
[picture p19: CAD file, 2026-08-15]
board/PCB_2026-08-15.dxf
designed by Ruben Muehlhans
|-CH11-|
|-CH10-|
|-CH9-|
|-CH8-|
|-CH7-|
|-CH6-|
|-CH5-|
|-CH4-|
|-CH3-|
|-CH2-|
|-CH1-|
SER
RCLK
SRCLK
6
7
8
15
2
0
4
16
17
5
18
19
GND
21
RX
TX
22
23
26
|----BEMF----|
5V
cmd
ad3
ad2
13
12
14
27
25
CH11
CH9|10
CH7|8
CH5|6
CH3|4
CH1|2
3.3V
DANGER
L
N
(c) 2021
07.2021
20210728
CH10
CH9
CH8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

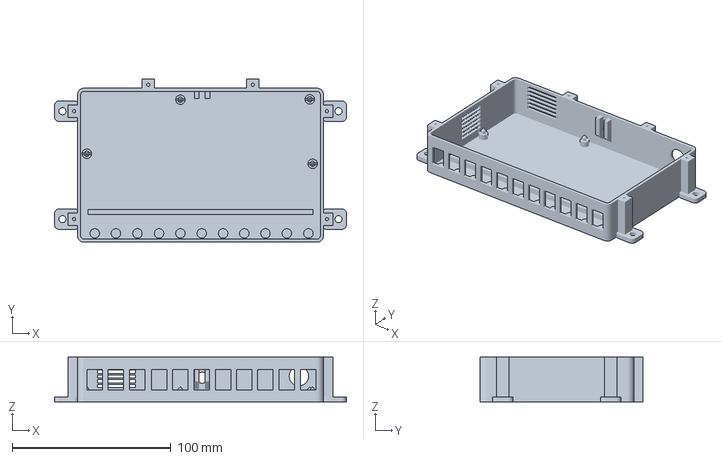
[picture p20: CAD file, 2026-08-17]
case/fussbodenheizung-schale-schnapper.3mf
184.0 x 102.9 x 28.2 mm

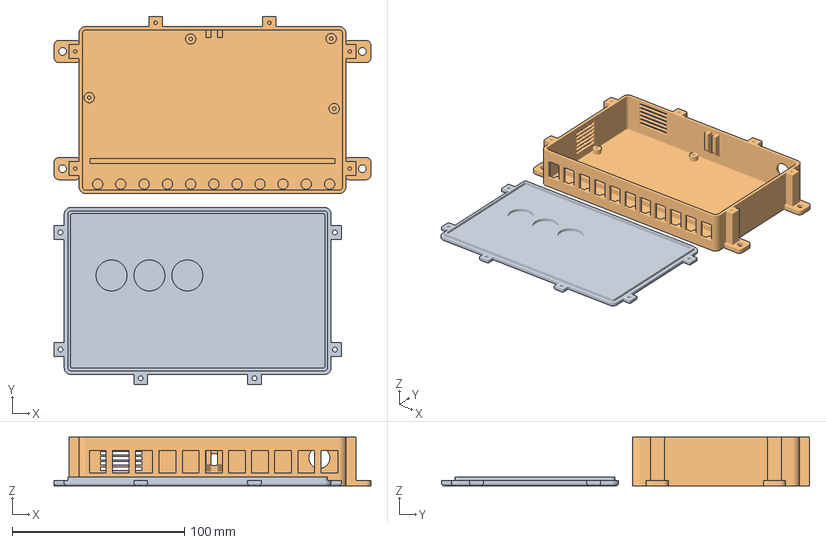
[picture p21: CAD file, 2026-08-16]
case/fussbodenheizung-gehaeuse-ohne-display.3mf
184.0 x 213.8 x 28.2 mm
Deckel (3 Farben)
Unterschale

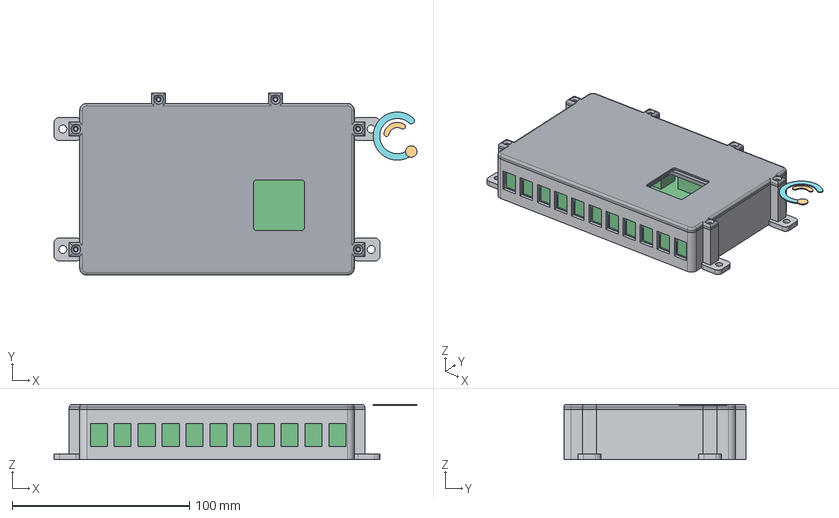
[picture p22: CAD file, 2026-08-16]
case/fbh_gehaeuse_schnapper.step
204.9 x 102.9 x 31.2 mm
unterschale
deckel
platine_dummy
displayrahmen
logo_ring
logo_akzent

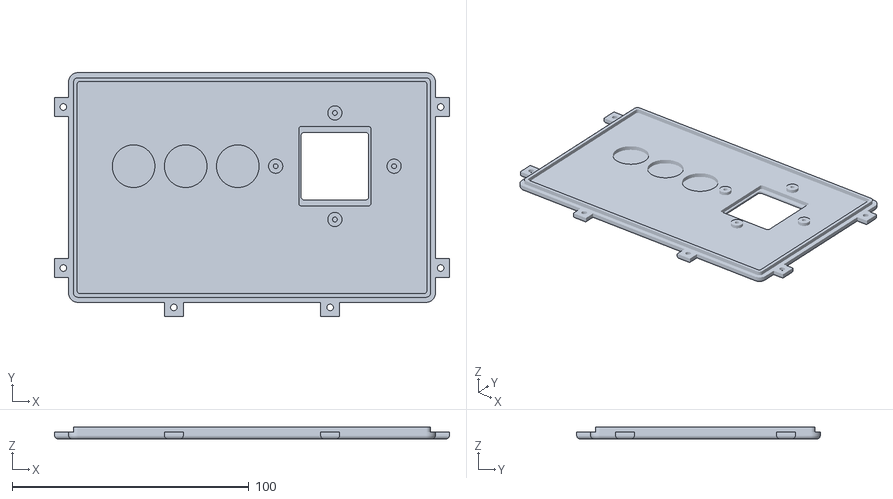
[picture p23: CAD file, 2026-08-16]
case/fbh_deckel.stl
166.8 x 102.9 x 5.00

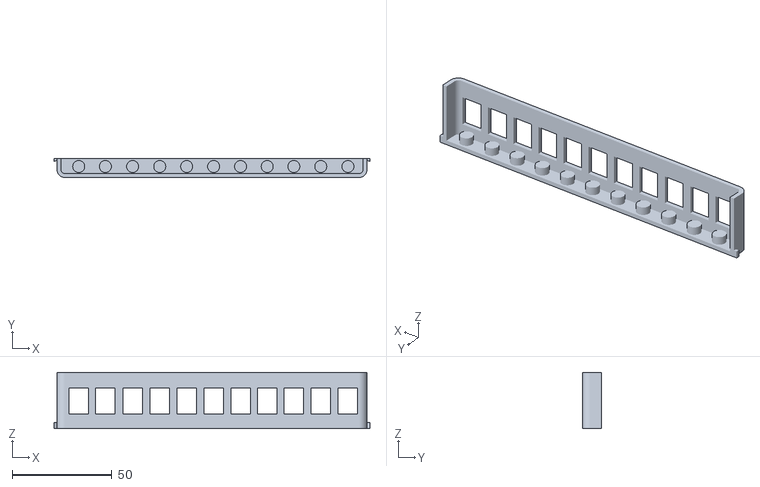
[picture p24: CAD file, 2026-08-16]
case/fbh_pruefstueck_suedwand.stl
158.0 x 9.50 x 28.2

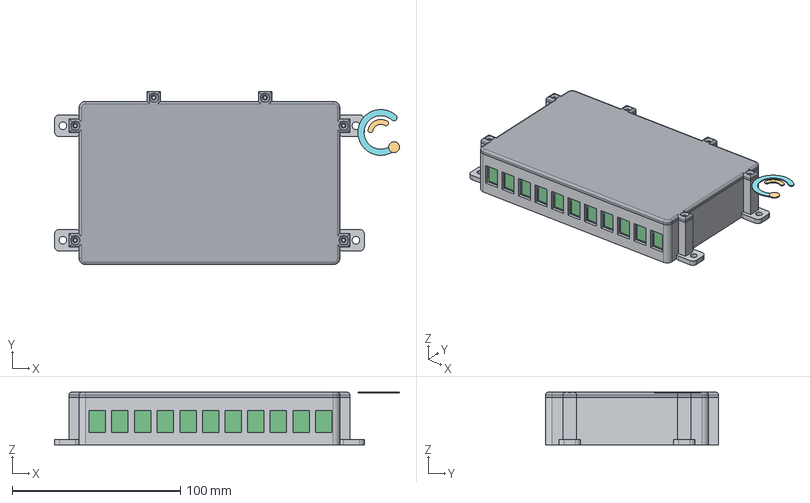
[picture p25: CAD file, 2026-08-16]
case/fbh_gehaeuse_ohne_display.step
204.9 x 102.9 x 31.2 mm
unterschale
deckel
platine_dummy
logo_ring
logo_akzent

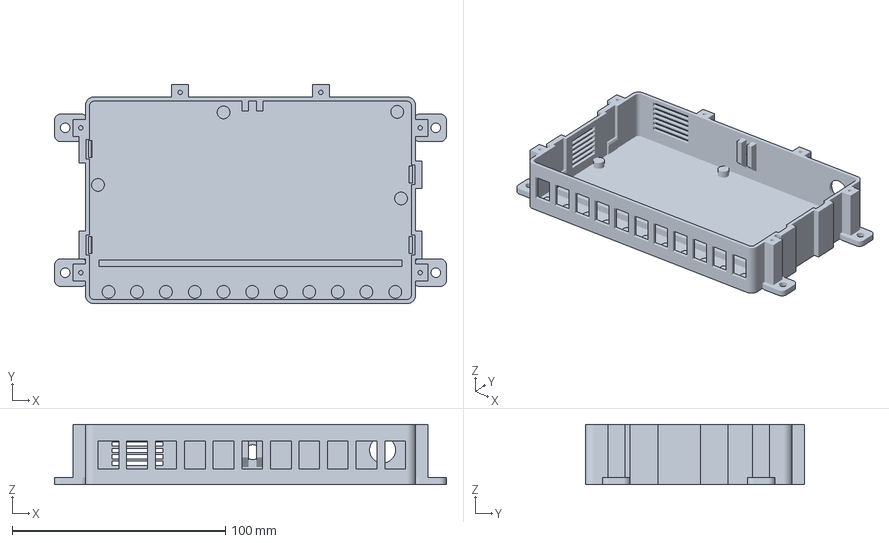
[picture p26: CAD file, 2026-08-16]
case/fussbodenheizung-schale-randclips.3mf
184.0 x 102.9 x 28.2 mm

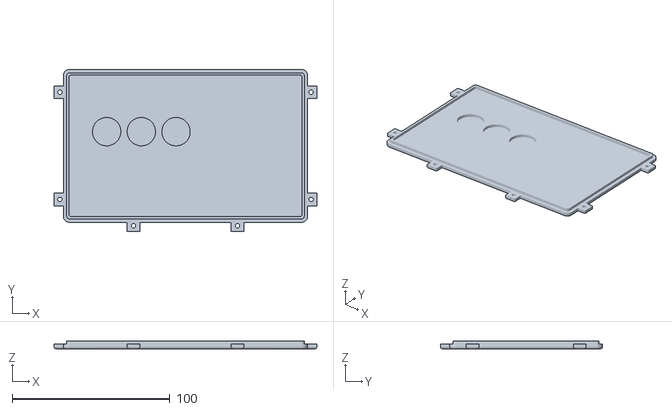
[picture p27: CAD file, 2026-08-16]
case/fbh_deckel_ohne_display_randclips.stl
166.8 x 102.9 x 5.00

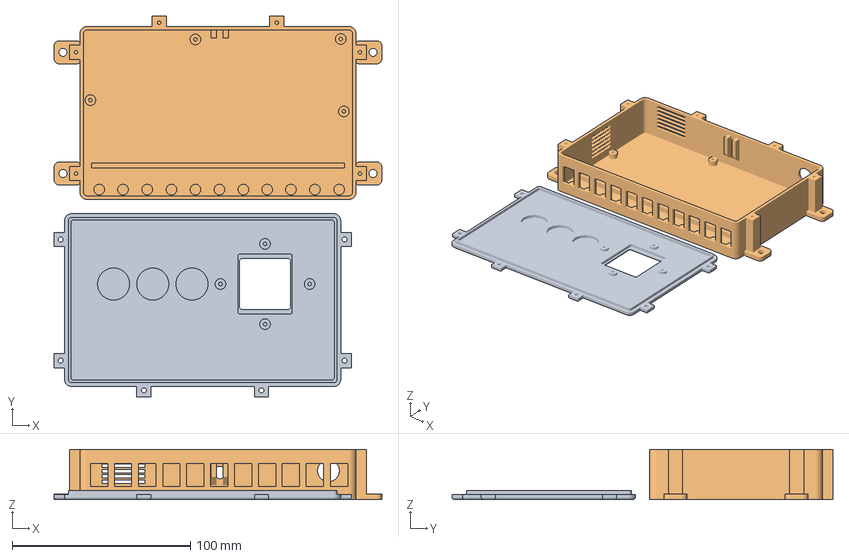
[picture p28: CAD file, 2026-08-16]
case/fussbodenheizung-gehaeuse.3mf
184.0 x 213.8 x 28.2 mm
Deckel (3 Farben)
Unterschale

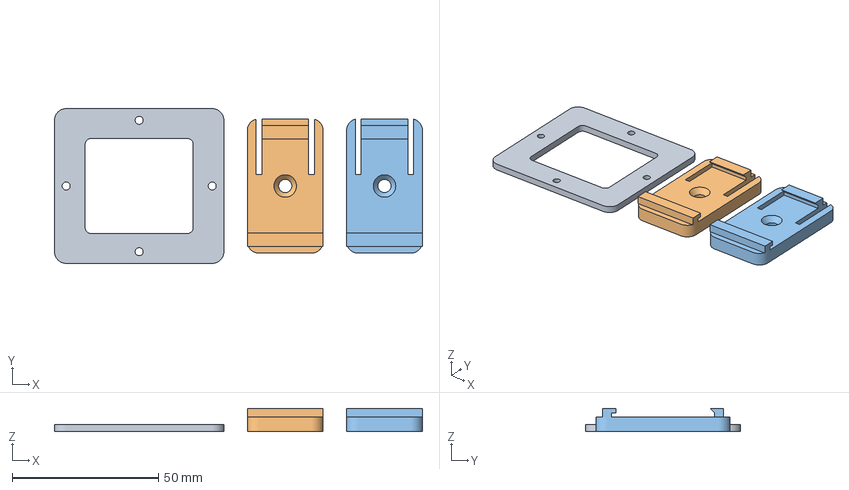
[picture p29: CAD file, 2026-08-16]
case/fussbodenheizung-zubehoer.3mf
126.0 x 53.0 x 8.00 mm
Displayrahmen
Hutschienen-Clip 1
Hutschienen-Clip 2

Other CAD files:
case/fbh_gehaeuse_randclips.step
case/fbh_unterschale.stl
case/fbh_unterschale_randclips.stl
case/fbh_displayrahmen.stl
case/fbh_gehaeuse.step
case/fbh_gehaeuse_ohne_display_randclips.step
case/fbh_gehaeuse_ohne_display_schnapper.step
case/fbh_hutschienen_clip.stl
case/fbh_logo_akzent.stl
case/fbh_logo_akzent_ohne_display_randclips.stl
case/fbh_logo_akzent_ohne_display_schnapper.stl
case/fbh_logo_akzent_randclips.stl
case/fbh_logo_akzent_schnapper.stl
case/fbh_logo_ring.stl
case/fbh_logo_ring_ohne_display_randclips.stl
case/fbh_logo_ring_ohne_display_schnapper.stl
case/fbh_logo_ring_randclips.stl
case/fbh_logo_ring_schnapper.stl
case/fbh_pruefstueck_display.stl
case/fbh_unterschale_schnapper.stl
case/fussbodenheizung-pruefstuecke.3mf

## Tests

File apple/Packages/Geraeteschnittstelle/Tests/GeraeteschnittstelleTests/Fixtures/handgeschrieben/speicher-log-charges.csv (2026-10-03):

beginn | dauer_s | brenner_s | starts | puffer_start | puffer_ende | kessel_vl_max | abgas_max | aussen_mittel | liter
1787834100 | 5820 | 3420 | 2 | 52.0 | 72.3 | 78.5 | 88.1 | 14.2 | 2.090
1787112600 | 4260 | 2880 | 1 | 51.4 | 68.5 | 74.0 | 81.6 |  | 1.760
1768468200 | 3900 | 2700 | 3 | 38.9 | 66.0 | 71.2 | 79.4 | -2.5 | 1.650

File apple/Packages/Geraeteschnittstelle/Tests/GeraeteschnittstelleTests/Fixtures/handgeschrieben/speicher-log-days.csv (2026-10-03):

datum | laufzeit_s | starts | liter | heizgradtage | aussen_min | aussen_max
2026-08-28 | 0 | 0 | 0.000
2026-08-27 | 3420 | 2 | 2.090 | 0.0 | 13.1 | 26.0
2026-08-26 | 0 | 0 | 0.000 | 0.2 | 11.8 | 23.1
2026-01-15 | 14400 | 6 | 8.800 | 18.3 | -6.2 | 1.4

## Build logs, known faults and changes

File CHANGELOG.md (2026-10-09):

# Änderungen

Die veröffentlichten Fassungen stehen mit Abbildern unter
[Releases](https://github.com/rubenmuehlhans/floor-heating-ctrl/releases).

## Unveröffentlicht

### Heizungsgeräte

- **Stromlose Relais sind keine Störung.** An dieser Anlage hängen die Tasmota-Relais hinter den
  Pumpenausgängen von Kesselregelung und Heliomat; schalten die ab, verschwindet das Relais aus
  dem Netz. Eine fehlende Verbindung gilt jetzt als stromlos: Pumpe steht, keine Abweichung, keine
  Vertauschungsprüfung, Meldung nur beim Wechsel statt bei jedem Versuch. `GET /api/state`
  führt `relay.unpowered` und `relay.unpowered_s`, je Heizkreis `blocked`, wenn die Pumpe laufen
  soll, das Relais aber stromlos ist. Oberfläche des Geräts und App zeigen „Relais ohne Strom“
  bzw. „von der Kesselregelung gesperrt“; die App meldet einen gesperrten Kreis nach einer
  Stunde als Hinweis statt das Relais als Störung.

### App

Ab Build 14 (9. Oktober, TestFlight):

- **Befund „Die Pumpe läuft, die Wärme kommt nicht an“.** Erkennt einen Heizkreis ohne Durchfluss,
  meist Luft in der Leitung bei zu niedrigem Anlagendruck. Mit einem 1-Wire-Fühler am versorgten
  Verteiler eindeutig (Vorlauf am Heizungsgerät mindestens 10 K über dem Verteiler, Warnung),
  ohne ihn als Hinweis (Rücklauf mindestens 14 K über den Räumen bei höchstens 6 K Spreizung).
  Beide nach einer halben Stunde. Abgeleitet aus Heizkreis 2 am 9. Oktober.
- **Stromlose Relais zählen nicht als Störung;** ein gesperrter Heizkreis erscheint nach einer
  Stunde als Hinweis (siehe Heizungsgeräte).
- **Keine Warnungen mehr mit dem iOS-27-SDK:** Hintergrundabruf über `submitTaskRequest`,
  Öffnen der Mitteilungseinstellungen auf dem Hauptthread.

## v0.6.0 — 5. Oktober 2026

### Verteiler

- **Betriebsart „Nur Außenfühler“.** Eine Platine ohne Stellantriebe, die nur den Außenfühler
  empfängt, braucht keinen Platzhalterraum mehr. Der Einrichtungsassistent fragt zuerst nach der
  Aufgabe; in dieser Betriebsart entfallen Räume, Kreise, Schutzfahrt, das Anfahren unbekannter
  Stellungen, Messfahrt und Fahrbefehle. Oberfläche und Anzeige zeigen den Außenfühler, Home
  Assistant erhält keine Ventile. Konfiguration: `outdoor_only`; `GET /api/state` meldet
  `device.function` mit `outdoor` oder `valves`.

### Leitstand

- **Außentemperatur von einer Verteilerplatine.** Empfängt der Leitstand den Außenfühler nicht
  selbst, übernimmt er den jüngsten Wert einer Verteilerplatine; `outdoor.source` nennt sie.
  Damit erscheint die Außentemperatur auch dann in HomeKit und auf der Anzeige.
- **HomeKit entfernt verwaiste Räume.** Führt ein erreichbarer Verteiler einen Raum nicht mehr,
  verschwindet das Thermostat aus Home.
- **Eigene Zeile im Protokoll auch bei vielen Funkthermometern.** Ab zehn Thermometern in
  Reichweite passte der Kopf der eigenen Zeile nicht mehr in den Puffer von 1280 Byte; die Zeile
  fehlte, das Protokoll meldete „Kopf zu lang“. Der Puffer fasst jetzt den Kopf für alle zwölf
  erfassten Thermometer, die Leser verwenden dieselbe Grenze.

### App

Ab Build 12 (5. Oktober, TestFlight):

- **Immer die neuesten Claude-Modelle.** Statt fester Kennungen fragt die App bei Anthropic ab,
  welches Opus-, Sonnet- und Haiku-Modell zuletzt erschienen ist, und verwendet diese; Auswahl,
  Assistent und Einstellungen zeigen den Namen mit Version, derzeit Claude Opus 5.5, Claude
  Sonnet 5.5 und Claude Haiku 4.5. Die Abfrage läuft höchstens einmal am Tag und bei „Verbindung
  prüfen“; ein laufendes Gespräch geht mit dem neueren Modell weiter. Die gespeicherte Modellwahl
  bleibt erhalten.
- **Claude Haiku wählbar.** Das schnellste und günstigste Claude-Modell, für kurze Auskünfte. Ob ein
  Modell adaptives Denken und eine Aufwandsstufe kennt, übernimmt die App aus der Modellliste;
  Haiku 4.5 antwortet ohne beides.
- **Rückgriff auf das bewährte Modell.** Weist die API ein neu erschienenes Modell mit 400 oder 404
  ab, beantwortet das zuletzt bewährte Modell derselben Reihe die Anfrage. Das abgewiesene Modell
  verwendet die App danach nicht mehr und meldet das einmal; ein noch neueres versucht sie wieder.
- **Sonnet mit Ersatzmodell.** Wie Opus erhält Sonnet ab 5.5 bei einer Ablehnung das von Anthropic
  empfohlene Ersatzmodell.

Ab Build 13 (5. Oktober, TestFlight):

- **Wärmepumpen-Check: Heizlast aus der Speicherwärme.** Neben der Verbrauchslinie, die über
  Brennerstunden, Düse und Wirkungsgrad rechnet, misst der Check die Wärme selbst: den
  Temperaturabfall des Speichers zwischen zwei Ladungen mal seinem Inhalt, gegen die
  Heizgradtage desselben Zeitraums. Daraus Heizlast, Wärmeverlust in W/K und Sockel je Tag; dazu
  die Ladeleistung in den Speicher und der Düsendurchsatz, der zu ihr passt. Der Inhalt des
  Speichers kommt aus `buffer.volumen_l`.

### Heizungsgeräte

- **Kein Neustart mehr bei jedem Ladungsbeginn.** Beim Brennerstart nach Verbrauch zieht das Gerät
  den Nullpunkt des Füllstands nach und speichert die Konfiguration. `cfg_set` legte dabei die
  bisherige Konfiguration, 2,7 KB, als Sicherung auf den Stapel des Brennerauftrags mit 4 KB, und
  der Stapel lief über. Seit dem 24. September starteten beide Geräte bei jeder großen Ladung neu,
  das am Kessel beim Brennerstart, das am Speicher wenige Minuten später; der Nullpunkt wurde nie
  gespeichert. `cfg_set` speichert jetzt zuerst und übernimmt danach, ohne Kopie auf dem Stapel,
  und der Brennerauftrag hat 6 KB. Die Verteiler-Firmware hatte dasselbe Muster und ist mit
  angepasst.
- **Kesselkreispumpe: Bei laufender Pumpe gilt der Rücklauf als Bezug.** Gegen den Speicherfühler
  gerechnet, der an dieser Anlage gut 3 K unter dem zurückkommenden Wasser lag, lief die Pumpe
  nach einer Ladung stundenlang weiter, obwohl der Kessel nichts abgab, und der Kessel zündete
  dabei mehrfach nach. Bei stehender Pumpe gilt weiter der Speicher, zuzüglich des zuletzt
  gemessenen Abstands zum Rücklauf.

### Gerät am Pufferspeicher

- **Befund „Vorlauf und Rücklauf vertauscht“ nur noch bei laufender Pumpe.** Die Haltezeit
  summiert jetzt nur beurteilbare Zeit. Bisher wurde vom ersten Auftreten an gemessen, sodass eine
  Standzeit mitzählte und der erste Wert nach dem Anlaufen, wenn noch das Wasser der Standzeit in
  den Rohren stand, die Meldung sofort auslöste. Geurteilt wird erst nach fünf Minuten
  Pumpenlauf, und nur, solange das Relais die Pumpe als eingeschaltet meldet. Bei stehender Pumpe
  wird der Befund nicht gemeldet.

## v0.5.0 — 3. Oktober 2026

### Leitstand

- **HomeKit-Brücke (Core2).** Je Raum ein Thermostat mit Ist, Soll (5 bis 35 °C in 0,5 K),
  Betriebsart, Heizzustand und Feuchte; Fühler für Außen, Pufferspeicher und Kesselvorlauf.
  Änderungen aus Home gehen nach 900 ms Sammelzeit an den Verteiler; ein nicht erreichbarer
  Verteiler zeigt in Home „Keine Antwort“. Code und QR-Code nur auf der Anzeige (Seite
  Leitstand, mittlere Taste kurz), erzeugt beim ersten Start. `POST /api/homekit/reset` löscht
  die Kopplungen; `GET /api/state` meldet den Stand unter `homekit`. Grundlage ist das
  esp-homekit-sdk von Espressif unter `third_party/`. Ohne PSRAM (Core Basic) bleibt HomeKit aus
  und belegt dort nur die rund 3 KB festen Speicher des SDK.
- **Sechs Seiten und Berührung (Core2).** Zu Anlage und Leitstand kommen Räume (Ist, Soll,
  Ventile, Feuchte), Verlauf (24 Stunden Speicher, Kessel, Außen, Brenner; mittlere Taste:
  Raumwerte), Meldungen (Befunde und Ereignisse des Tages) und Geräte (Erreichbarkeit, WLAN,
  Laufzeit, Speicher, Fassung, Außenfühler; mittlere Taste: Funkthermometer). Wischen blättert,
  Tippen auf den Fuß wirkt wie die Tasten. Der Verlauf liegt im PSRAM und wird nach einem Neustart
  von der Karte gefüllt. Ein neuer Befund schaltet die Anzeige ein und zeigt die Meldungen. Am
  Core Basic bleibt es bei zwei Seiten.
- **Echtzeituhr und Versorgung (Core2).** Die Zeit kommt nach einem Stromausfall aus der
  Echtzeituhr, das Protokoll schreibt ohne Lücke weiter. Ereignisse `versorgung_aus` und
  `versorgung_wieder` mit Ladestand; die Seite Leitstand zeigt Netz oder Akku.

- **Neues Gerät, `apps/station`.** Ein M5Stack Core zeigt den Zustand der Anlage auf zwei Seiten
  (Anlage, Leitstand), fragt Heizungsgeräte und Verteilerplatinen alle 30 s ab, empfängt
  Funkthermometer samt verschlüsselter BTHome-Geräte und liefert die Außentemperatur unter
  `GET /api/demand`. mDNS-Rolle `station`, Kennung `lst_…`. Einrichtung über den Zugangspunkt
  `leitstand-XXXX`, Oberfläche mit Übersicht, Funk, Einstellungen und System, Abbild des
  Bildschirms unter `GET /api/screen`. Aufzeichnung auf SD-Karte und HomeKit folgen; siehe
  `docs/konzept-leitstand.md`.
- **Protokoll auf der SD-Karte.** Je Tag in UTC ein Verzeichnis `protokoll/<jahr>/<tag>/` mit
  Messwerten je Gerät im Takt der Abfrage, Fünfminutenmitteln, Ereignissen (Neustart mit Grund,
  Erreichbarkeit, Firmware, Brenner und Pumpen mit Dauer, Sollwerte, Betriebsarten, Befunde),
  vollständigen Zuständen alle 15 Minuten und `geraete.json`. Spalten nach
  `docs/katalog-messgroessen.md`; eine neue Spalte beginnt eine Datei `<kennung>.2.csv`. Ohne
  gestellte Uhr wird nichts geschrieben. Unter 10 Prozent freiem Platz gehen die ältesten
  Zustände und Rohwerte. Abruf unter `GET /api/log/days` und `GET /log/<tag>/<datei>` mit
  `Range`, Reiter **Protokoll** in der Oberfläche, Kartenstand auf dem Bildschirm.
- **Protokolle der Heizungsgeräte** werden einmal am Tag vollständig nach
  `protokolle/<kennung>.ladungen.csv` und `.tage.csv` übernommen, über eine Zwischendatei.
- **Funkereignisse:** Thermometer verloren, wieder empfangen, Schlüssel falsch.
- **Auswertung am Gerät:** `GET /api/log/series` (Mittel ausgewählter Messgrößen in wählbarem
  Raster) und `GET /api/log/events` (Ereignisse eines Zeitraums).
- **Absturzspeicher über das Netz:** `GET /api/coredump` mit Task, Programmzähler, Ursache und
  Rücksprungadressen.
- **Kartenwechsel im Betrieb.** Alle zehn Sekunden und nach jedem Schreibfehler fragt der
  Leitstand den Status der Karte ab. Antwortet sie nicht, gibt er die Einbindung auf, statt mit der
  Belegungstabelle der alten Karte auf eine neue zu schreiben, und bindet neu ein.
- **Karte formatieren.** `POST /api/log/format` mit Bestätigung und ein Knopf unter **Protokoll**
  formatieren die ganze Karte als eine FAT32-Partition, etwa eine Karte von einem Raspberry Pi, von
  der vorher nur die kleine Startpartition lesbar war.
- **Verklemmung von Anzeige und Protokoll behoben.** Die Anzeige hielt beim Zeichnen die Sperre des
  Busses und fragte den Stand des Protokolls ab; die Kartenprüfung hielt die Sperre des Protokolls
  und wollte den Bus. Unter Last blieben Anzeige, Protokoll und Abfrage stehen, die Oberfläche
  antwortete leer. Unter der Sperre des Protokolls wird der Bus nicht mehr gesperrt.
- **Lautsprecher still.** Der Verstärker des Core Basic hängt an GPIO 25 und ist immer versorgt;
  offen gelassen, pfiff und knisterte er unter Last auf der Karte. Der Pin liegt jetzt fest auf null.
- **Dauerlastprüfung.** `POST /api/log/lasttest {"mb":1024}` schreibt ein Muster auf die Karte,
  während Anzeige und Protokoll weiterlaufen, liest es zurück und vergleicht; `GET` liefert den Stand.
- **Bildschirmabzug unter der Speichersperre**, damit er nicht mit dem Auswerten eines
  Gerätezustands zusammenfällt.
- **Update ohne Abfrage.** Während einer Firmware-Übertragung ruht die Abfrage der Anlage. Beides
  zusammen brauchte mehr Arbeitsspeicher, als der Core Basic hat: Übertragungen brachen ab, der
  freie Speicher fiel auf 376 Byte.
- **Core2 ohne Neustartschleife.** Mit Heimnetz und HomeKit lief der interne Arbeitsspeicher des
  Core2 nach dem Anlegen der Zubehöre auf unter 7 KB; dann fehlten Puffer der Karte und Sperren,
  und `fopen` brach mit `abort()` ab, etwa alle 20 Sekunden. Gewöhnliche Anforderungen, TLS und
  NimBLE gehen jetzt zuerst in den PSRAM (`SPIRAM_MALLOC_ALWAYSINTERNAL=0`); intern bleiben rund
  39 KB frei. Der Core Basic ohne PSRAM ist davon nicht berührt.

### App

Ab Build 7 der App (23. September, TestFlight).

- **Abgleich mit dem Leitstand.** Die App übernimmt die Fünfminutenmittel aus dem Protokoll des
  Leitstands in ihren Verlauf, beim Verbinden und danach alle fünf Minuten; vom laufenden Tag nur
  die neuen Zeilen über `Range`. Die Werte des Leitstands haben Vorrang vor der eigenen
  Aufzeichnung. Der Stand je Leitstand liegt in `Abgleich-<kennung>.json` und wird nach jeder Datei
  gesichert. Anzeige unter Geräte › Leitstand › Verlauf.
- **Ereignisse im Verlauf.** Die Ereignisse des Leitstands liegen je Tag in der Verlaufsablage.
  Heizung › Verlauf markiert Neustarts, Firmwarewechsel, neue Befunde und Ausfälle im Diagramm und
  listet sie darunter mit Grund und Dauer; der Verlauf eines Raums markiert Ein- und Ausschalten.
  Ist eine Datei auf dem Leitstand kürzer als das Übernommene, liest die App den Tag neu. Nach
  **Verlauf löschen** beginnt der Abgleich von vorn und übernimmt die Karte erneut.

Ab Build 8 (23. September, TestFlight):

- **Verlauf in Tafeln.** Heizung › Verlauf zeigt je Gruppe ein eigenes Diagramm mit eigener
  Skala: Kessel und Speicher, Abgas, Brenner und Speicher, jeder Heizkreis, Räume, Vorlauf an den
  Verteilern. Ein Heizkreis zeigt Vor- und Rücklauf, dazwischen die Spreizung als Fläche, grau
  hinterlegt den Pumpenlauf und zuschaltbar die Außentemperatur auf einer festen rechten Achse von
  −10 bis 20 °C; alle Heizkreise teilen eine Skala. Tippen oder Ziehen wählt eine Zeit, die in allen
  Tafeln stehen bleibt; die Legende blendet Reihen aus und ein.
- **Heizkurve je Heizkreis.** Die Karte des Heizkreises führt zu Verlauf und Heizkurve: Vor- und
  Rücklauf über der Außentemperatur, je Platz ein Punkt, nur solange die Pumpe lief, mit
  Ausgleichsgerade, Steigung in K je K, Vorlauf bei 0 °C außen und Bestimmtheit.

Ab Build 9 (23. September, TestFlight):

- **Werkzeuge des Assistenten.** `ereignisse` liest die Ereignisse bis 90 Tage mit
  Zusammenfassung je Art und Gerät (Starts und Laufzeiten, Neustartgründe, Ausfalldauer).
  `feinverlauf` holt Messwerte im Takt der Abfrage vom Leitstand, bis 24 Stunden, auch freien
  Speicher und WLAN-Empfang. `verlauf` reicht bis ein Jahr, über 30 Tage in Tagesmitteln.
- **Analysepaket.** Einstellungen › Daten erzeugt ein ZIP mit je Gerät einer CSV-Datei im
  gewählten Raster, den Ereignissen, dem Katalog der Messgrößen und einer Beschreibung der Anlage,
  zum Teilen; ohne Adressen und Zugangsdaten.

Ab Build 10 (24. September, TestFlight):

- **Wärmepumpen-Check** unter Heizung › Auswertung: Heizlast bei der Normaußentemperatur aus der
  Verbrauchslinie, Wärmeverlust in W/K, Warmwasseranteil, Kalibrierung des Düsendurchsatzes über
  Tankablesungen, nötige Vorlauftemperatur je Heizkreis mit Bewertung nur bei belastbarer
  Heizkurve, Räume, die bei Kälte trotz offener Ventile unter dem Sollwert bleiben.

Ab Build 11 (24. September, TestFlight):

- **Seite der Anzeige** am Core2 aus allen sechs wählbar (Menü), am Core Basic wie bisher Anlage
  oder Leitstand.
- **HomeKit im Leitstand:** Geräte › Leitstand zeigt gekoppelte Geräte und Zubehör und löscht
  die Kopplungen nach Rückfrage. Den Code zeigt die App bewusst nicht.
- Ereignisse `versorgung_aus` und `versorgung_wieder` und die Kartenereignisse des Leitstands in
  Worten.
- **Leitstand über seinen Zugangspunkt einbinden:** Einrichtung › Neues Gerät bietet neben Verteiler
  und Heizungsgerät den Leitstand an. Die App tritt dem offenen Netz `leitstand-XXXX` bei, schreibt
  Ort und WLAN-Zugang und nimmt den Leitstand danach in die eigene Liste auf.
### Alle Geräte

- **Falsche WLAN-Zugangsdaten lassen sich berichtigen.** Scheiterte die Verbindung, versuchte das
  Gerät es alle fünf Sekunden erneut. Jeder Versuch zieht den Einrichtungs-Zugangspunkt auf den
  Kanal des Heimnetzes; verbundene Telefone flogen hinaus, eine Berichtigung war kaum möglich.
  Bei offenem Zugangspunkt jetzt alle 30 Sekunden, solange jemand daran hängt alle fünf Minuten.
  Erst mit dem nächsten Update in Verteiler und Heizungsgerät.
- **Neustart ohne Absturz.** Der Neustart nach einem Update oder über die Oberfläche lief in einer
  Aufgabe mit 2 KB Stapel. `esp_restart()` ruft dort die Abschaltroutinen von WLAN und Bluetooth
  auf; am Leitstand lief der Stapel über, der Absturzspeicher zeigte „Stack overflow“ in
  `restart`, und der Neustart geschah als Absturz. Jetzt 4 KB, in allen drei Firmwares.
- **Neustartgrund.** `GET /api/state` nennt `reset_reason`: `power_on`, `software`, `panic`,
  `task_wdt`, `brownout` und weitere. Am 23. September starteten Kessel und Speicher ohne
  erkennbaren Grund neu; solche Fälle lassen sich damit einordnen.

### Verteilerplatine

- **Abstand zum Anschlag auf.** Gewöhnliche Fahrten öffnen höchstens bis 92 % des Hubs. Die
  Fahrzeit auf aus der Messfahrt reicht bis zum Anschlag; jede Fahrt auf 100 % endete deshalb
  dort, wo ein Steg am Zahnrad den Nippel des Stößels abfängt. Das Blockiermoment ging dabei in
  die Stößelführung des HmIP-VDMOT, das Teil, das an diesen Antrieben bricht. Die Schutzfahrt
  öffnet ebenfalls nur bis 92 % und fährt allein zu auf Anschlag. Notfahrt und Messfahrt fahren
  weiterhin in den Anschlag.
- **Entlastung nach dem Schließen.** Nach einer Fahrt zu, die an der Endlage oder an der
  Maximallaufzeit endet, fährt der Antrieb eine Sekunde wieder auf, etwa 0,1 mm. Die Spindel ist
  selbsthemmend; bisher blieb die volle Blockierkraft danach auf Ventilstift und Dichtung stehen.
  Das Ventil bleibt geschlossen, die Stellung bei 0 %.
- **1-Wire-Treiber 1.1.2.** Die Bauteilverwaltung von Espressif löst `onewire_bus` jetzt zu 1.1.2
  auf. Die ROM-Suche zählt die Bits nach AN187 ab 1, die Ruhezeit nach dem Rücksetzen beträgt 480 µs
  wie in der Spezifikation.

### Heizungsgerät

- **Außentemperatur vom Leitstand.** Das Heizungsgerät fragt zuerst einen Leitstand und erst
  danach die Verteilerplatinen. Solange der Wert des Leitstands frisch ist, übernimmt die
  Pumpensteuerung keinen Außenwert aus den Bedarfsantworten der Verteiler; die Quelle wechselte
  sonst alle paar Sekunden.
- **Kesselkreispumpe läuft, solange der Brenner läuft.** Sie schaltet ein, sobald die
  Brennererkennung den Brenner meldet, ohne Haltezeit und auch in einer Mindestpause, und geht
  erst aus, wenn die Erkennung ihn als aus meldet und danach die Spreizung über die Haltezeit
  darunter liegt. Bisher entschied allein der Abstand zwischen Kesselvorlauf und Speicher. Am
  23. September lag er während eines Brennerlaufs bei 0,9 bis 2,5 K, die Pumpe stand, und der
  Kessel schaltete den Brenner nach gut zwölf Minuten selbst ab; der Speicher stieg um 2,3 K,
  bei den Ladungen zuvor um 12 bis 19 K. Neuer Grund `burner`.
- **Neustart schaltet die Kesselkreispumpe nicht mehr ab.** Beim ersten Rechenschritt nach einem
  Neustart galt die Einschaltschwelle von 3 K; eine Pumpe, die bei 2,5 K Abstand lief, ging mit
  dem Neustart sofort aus. Die Regel beginnt jetzt bei laufender Pumpe und schaltet frühestens
  nach der Haltezeit ab.
- **Brennererkennung über einen Neustart.** Brennerzustand und Bezugslinie werden mit den
  Tageswerten gesichert. Lief der Brenner beim letzten Sichern und ist das Abgasrohr noch warm,
  gilt er nach dem Neustart weiter als laufend, ohne zweiten Start. Bisher begann die
  Bezugslinie am heißen Rohr, und ein laufender Brenner wurde erst nach weiteren 12 K Anstieg
  erkannt, gegen Ende eines Laufs gar nicht; am 23. September vergingen gut vier Minuten. Ein
  Eintrag der Tageswerte aus 0.4.0 wird weiter gelesen.

### Werkzeuge und Dokumentation

- **Attrappe des Leitstands**, `tools/mock_station.py`, mit einem verschlüsselten Climate-Sat und
  zwei offenen Thermometern; `apple/Werkzeuge/attrappen.sh` startet sie auf Port 8325. Sie liefert
  Brennerläufe im Zweistundentakt und Ereignisse mit Neustart, Ausfall, Firmwarewechsel und
  Befund, damit Abgleich und Markierungen im Simulator prüfbar sind.
- `tools/mock_heatsource.py` meldet eine Verbrauchslinie (`trend`), und das Tagesprotokoll folgt ihr;
  damit lässt sich der Wärmepumpen-Check im Simulator prüfen.
- **Handbuch:** Kapitel Leitstand; Kesselkreispumpe mit Brennerregel und Neustart.
- **Prüfungen:** 649 (v0.4.0: 578), darunter der Brennerlauf vom 23. September mit den gemessenen
  Werten; dazu 137 für das Protokoll des Leitstands (`test/host/test_protokoll.c`) gegen
  anonymisierte Zustände der Anlage.
- **Katalog der Messgrößen**, `docs/katalog-messgroessen.md`, für Leitstand und App.
- **`tools/protokoll_pruefen.py`** prüft das Protokoll eines Tages auf der Karte: Spalten,
  Zeitfolge, JSON, Abtastungen je Gerät, unbelegte Lücken.
- **Prüfungen des Protokolls:** 137, dazu das Lesen der eigenen Dateien.

## v0.4.0 — 22. September 2026

### Verteilerplatine

- **Verschlüsselte BTHome-Thermometer.** Der Verteiler empfängt BTHome in Fassung 2, offen und
  mit AES-128-CCM verschlüsselt, etwa vom Climate-Sat von camperSense. Den Schlüssel je Gerät,
  32 Hexadezimalziffern aus der camperSense-App, nimmt die Oberfläche unter **Sensoren**
  entgegen, die Schnittstelle unter `POST /api/ble/key`. Bis zu 16 Schlüssel liegen in einem
  eigenen Eintrag im NVS, nicht in der Konfiguration; `GET /api/ble` nennt den Stand je Gerät
  („fehlt", „falsch", „passt") und die Adressen mit Schlüssel. Die Sicherung trägt die Schlüssel
  im Klartext, das Zurückspielen übernimmt sie, die Werksvorgabe löscht sie. Ein Rahmen mit
  einem nicht höheren Zähler als der zuletzt angenommene bleibt ohne Wirkung, nach zehn Minuten
  ohne gültigen Rahmen gilt er wieder. Werte, die ein Gerät auf mehrere Rahmen verteilt, werden
  feldweise übernommen.
- **Bluetooth gibt dem WLAN Funkzeit zurück.** WLAN und Bluetooth teilen sich ein Funkteil, und
  die Suche nach Thermometern belegte es durchgehend. Die Anmeldung am Einrichtungs-Zugangspunkt
  einer frischen Platine gelang deshalb erst nach mehreren Versuchen. Die Suche belegt das
  Funkteil jetzt zu 30 Prozent und ruht, solange nur der Zugangspunkt läuft; die Anmeldung
  gelingt beim ersten Versuch. Am Erdgeschoss gemessen sind die Messwerte der Thermometer
  dadurch im Mittel 24,7 statt 9,5 s alt, höchstens 112 statt 61 s; die Zeitgrenze liegt bei
  900 s.
- **Bedarf nur aus geregelten Kreisen.** Wärmebedarf melden nur noch Räume, die eingeschaltet
  sind und einen Messwert haben. Kreise ohne Raum zählten bisher mit; weil sie nach dem ersten
  Start auf Anschlag offen stehen, meldeten alle drei Verteiler dauerhaft Bedarf. Von Hand
  gehaltene Ventile zählen weiterhin.
- **Kreise ohne Raum fahren zu.** Einmal in der Minute wird geprüft, ob ein Kreis ohne Raum offen
  steht. Von Hand gehaltene Kreise, Messfahrt und Schutzfahrt bleiben unberührt.
- **Kennwort des Zugangspunkts.** Ein Kennwort unter acht Zeichen wird abgewiesen. Bisher öffnete
  das Gerät den Zugangspunkt in diesem Fall ohne Kennwort, ohne darauf hinzuweisen. Ebenso wird
  MQTT ohne Adresse des Brokers nicht mehr eingeschaltet — beides wie beim Heizungsgerät.

### Heizungsgerät

- **Brennerende am Ausschlag.** Die erste Brennerfahrt der Anlage dauerte laut Gerät vier Stunden
  und sechs Minuten, tatsächlich rund fünfzig Minuten: Ein warmer Kessel hält das Abgasrohr
  dauerhaft über der Ausschaltschwelle. Aus ist der Brenner jetzt auch, wenn das Abgas um 6 K
  unter den Höchstwert der Fahrt fällt; an ist er, wenn es über der Bezugslinie liegt und um
  6 K über den Tiefstwert gestiegen ist. Neue Einstellung `burner.swing_k`.
- **Kesselkreispumpe gegen den Speicher.** Verglichen wird der Kesselvorlauf mit der
  Speichertemperatur, ersatzweise mit dem Rücklauf. Bei stehender Pumpe gleichen sich Vor- und
  Rücklauf an, und ein Kessel mit Restwärme blieb stehen, obwohl der Speicher kälter war.
- **Kesselkreispumpe früher aus.** Die Schwellen gehen von 1,0/0,5 K auf 3,0/2,0 K. Mit 0,5 K lief
  die Pumpe nach dem Brennerende fünf Stunden weiter und hielt nur noch den Kessel auf
  Speichertemperatur; der Speicher hatte seinen Höchststand bei genau 2 K Abstand erreicht.
- **Nullpunkt des Füllstands am Brennerstart.** Läuft der Brenner an, nachdem der Speicher um
  mindestens 3 K gefallen ist, wird der Nullpunkt zu 40 Prozent an den Speicherwert
  herangeführt. Neue Einstellungen `buffer.leer_lernen`, `buffer.lern_drop_k`,
  `buffer.leer_epoch`. Leer- und Vollpunkt sind in der Oberfläche einstellbar.
- **Kalter Anlauf ist keine fertige Ladung.** „Geladen" verlangt zusätzlich einen Kesselvorlauf
  über `buffer.kessel_hot_c` (60 °C). Beim Anfahren aus dem kalten Kessel lagen Vor- und
  Rücklauf 400 s lang dicht beieinander, und die Ladung galt nach wenigen Minuten als fertig.
- **Rückströmung.** Steigt der Kesselrücklauf bei stehender Pumpe und ausgeschaltetem Brenner um
  mindestens 3 K, meldet das Gerät den Befund `backflow`. Beobachtet bei einer
  Warmwasserzapfung: 36,9 auf 46,3 °C bei 32 °C im Vorlauf.
- **Warmwasserzapfungen.** Ein Einbruch des Speichers um mindestens 2 K in 15 Minuten zählt als
  Zapfung, außerhalb von Ladungen. Mit eingetragenem Speicherinhalt auch in Kilowattstunden.
  Neue Einstellungen `buffer.zapf_drop_k`, `buffer.zapf_win_s`, `buffer.volumen_l`.
- **Alle Einstellungen in der Oberfläche.** Sechzehn von vierundvierzig Werten waren nur über die
  Schnittstelle erreichbar, darunter die gesamte Brennererkennung.
- **Tageswerte gesichert.** Während eines Brennerlaufs werden Laufzeit und Starts alle fünf
  Minuten gesichert. Ein Neustart mitten im Lauf verlor bisher die ganze Ladung aus der
  Tagesbilanz.
- **Aufzeichnung übersteht einen Neustart.** Eine scharf geschaltete Aufzeichnung bleibt es.
- **Verlauf bleibt erhalten**, wenn ein Messwert des Nachbargeräts ausfällt. Bisher begann er
  dann von vorn; nach acht Stunden standen vier Messpunkte statt zweihundertfünfzig.
- **Anlagenschema.** Heizkreise des Nachbargeräts erscheinen blass mit ihren Werten, die Pumpe
  ist mit ihrem Zustand beschriftet.
- **`POST /api/system/clear-logs`** verwirft Protokolle und Tageswerte, etwa nach einer Zeit mit
  falscher Erkennung.

### Behoben

- **Vorgaben der Kesselkreispumpe.** Die Einstellungsablage gab einem neu eingerichteten Gerät
  noch 1,0/0,5 K, während Rechenmodul und Prüfungen mit 3,0/2,0 K arbeiteten.
- **`burner.swing_k`** wurde nicht an die Brennererkennung übergeben; eine Änderung blieb
  wirkungslos.
- **Fühler über die Schnittstelle.** Eine Teilangabe, etwa nur Kennung und Rolle, setzte den
  Korrekturwert auf 0. Fehlende Felder behalten jetzt ihren Wert.
- **Fehlende Prüfungen.** Das Heizungsgerät nahm täglichen Neustart, Haltezeiten der
  Brennererkennung, Leer-, Voll- und Warnwert, „Vorlauf heiß", Haltezeit für „geladen" und das
  Zapfungsfenster ohne Prüfung an. Es gelten jetzt die Grenzen, die die Oberfläche schon anzeigte.
  Umgekehrt ließ die Oberfläche als Abfrageabstand der Verteiler bis 600 s zu, das Gerät nimmt
  höchstens 300 s.
- **Meldung zur Busbelegung.** Das Protokoll verlangte nach einer Änderung einen Neustart; die
  Fühlererfassung stellt aber sofort um.
- **Grund der stehenden Kesselkreispumpe.** Er lautete „Rücklauf wärmer als Vorlauf", nach der
  Regel bis zum 18. August. Seitdem wird der Kesselvorlauf mit dem Speicher verglichen; der
  Grund heißt jetzt „Kessel kaum wärmer als der Speicher".

### Werkzeuge und Dokumentation

- **`tools/check_defaults.py`** vergleicht Vorgabewerte, die an zwei Stellen stehen:
  Einstellungsablage und Rechenmodule des Heizungsgeräts, dazu die Werte, mit denen die
  Verteiler-Oberfläche einen neuen Raum anlegt.
- **Handbuch.** Jede Einstellung beider Gerätetypen mit Schlüssel, Vorgabe, zulässigem Bereich
  und Bedeutung; Befunde mit ihren Kennungen und Auslösebedingungen; Proportionalband richtig
  beschrieben (am Sollwert halb offen).
- **Attrappe des Verteilers** mit einem verschlüsselten Climate-Sat, der erst mit dem
  Testschlüssel der Prüfungen Werte liefert, samt `POST /api/ble/key` und Schlüsseln in der
  Sicherung.
- **Prüfungen:** 578 (v0.3.0: 483), darunter AES-128 nach FIPS-197 und BTHome-Rahmen aus dem
  Rahmenbau der Satelliten-Firmware.

## v0.3.0 — 17. August 2026

Zweite Fassung mit Heizungsteil: Kesselkreispumpe, Auswertung der Protokolle (Verbrauchslinie,
Abgas-Vorlauf-Abstand), Plausibilitätsprüfungen der Fühler, Sicherung und Wiederherstellung der
Einstellungen, Außentemperatur für die Heizungsgeräte. Fertige Abbilder und Web-Flasher.
[Versionshinweise](https://github.com/rubenmuehlhans/floor-heating-ctrl/releases/tag/v0.3.0)

## v0.2.0 — 16. August 2026

[Versionshinweise](https://github.com/rubenmuehlhans/floor-heating-ctrl/releases/tag/v0.2.0)

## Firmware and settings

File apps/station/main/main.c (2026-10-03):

/*
 * Leitstand: Funkempfang, Anzeige, Protokoll und -- auf dem Core2 mit
 * PSRAM -- HomeKit fuer die Fussbodenheizung.
 *
 * Der Leitstand regelt nichts. Er fragt Heizungsgeraete und Verteiler ab,
 * empfaengt den Aussenfuehler ueber Bluetooth und reicht dessen Wert an die
 * Heizungsgeraete weiter. Siehe docs/konzept-leitstand.md.
 */

#include <string.h>

#include "atc_ble.h"
#include "esp_app_desc.h"
#include "esp_log.h"
#include "esp_ota_ops.h"
#include "netmgr.h"
#include "peers.h"
#include "st_config.h"
#include "st_hap.h"
#include "st_log.h"
#include "st_poll.h"
#include "st_ui.h"
#include "st_web.h"

static const char *TAG = "app";

static void on_ble_measurement(const atc_device_t *dev, void *ctx)
{
    (void)ctx;
    st_poll_ble(dev);
}

void app_main(void)
{
    const esp_app_desc_t *desc = esp_app_get_description();
    ESP_LOGI(TAG, "Leitstand, Version %s (%s %s)", desc->version, desc->date, desc->time);

    ESP_ERROR_CHECK(st_cfg_init());
    st_poll_init();

    /* Die Anzeige zuerst: Sie zeigt den Start und, solange kein WLAN
     * eingerichtet ist, wie die Einrichtung geht. Ohne Anzeige laeuft der
     * Rest trotzdem. */
    if (st_ui_start() != ESP_OK) {
        ESP_LOGW(TAG, "Anzeige nicht verfuegbar");
    }
    /* Die Karte haengt am Bus der Anzeige und kommt deshalb danach. Fehlt
     * sie, versucht es das Protokoll jede Minute erneut. */
    ESP_ERROR_CHECK(st_log_start());

    st_config_t cfg;
    st_cfg_copy(&cfg);
    netmgr_cfg_t netz;
    st_cfg_netmgr(&cfg, &netz);
    ESP_ERROR_CHECK(netmgr_start(&netz));

    char id[24];
    st_device_id(id, sizeof(id));
    if (peers_start(cfg.wifi.hostname, cfg.site, id, PEERS_ROLE_STATION) != ESP_OK) {
        ESP_LOGW(TAG, "Suche nach den Geraeten der Anlage nicht verfuegbar");
    }
    ESP_ERROR_CHECK(st_poll_start());

    /* Schluessel im eigenen Namensraum; der Verteiler nutzt "fbh". Bluetooth
     * und WLAN teilen sich den Funkteil: Solange nur der
     * Einrichtungs-Zugangspunkt da ist, gehoert er dem WLAN. */
    ESP_ERROR_CHECK(atc_ble_keys_init("station"));
    netmgr_set_setup_hook(atc_ble_pause);
    ESP_ERROR_CHECK(atc_ble_start(on_ble_measurement, NULL));

    ESP_ERROR_CHECK(st_web_start());

    /* HomeKit nach peers, das mDNS schon gestartet hat; ohne PSRAM (Core
     * Basic) bleibt es aus, ein Fehler haelt den Rest nicht auf. */
    if (st_hap_start() != ESP_OK) {
        ESP_LOGW(TAG, "HomeKit nicht verfuegbar");
    }

    memset(&cfg, 0, sizeof(cfg));
    memset(&netz, 0, sizeof(netz));

    /* Eine frisch eingespielte Firmware gilt erst nach diesem Punkt. */
    const esp_partition_t *running = esp_ota_get_running_partition();
    esp_ota_img_states_t state;
    if (esp_ota_get_state_partition(running, &state) == ESP_OK && state == ESP_OTA_IMG_PENDING_VERIFY) {
        if (esp_ota_mark_app_valid_cancel_rollback() == ESP_OK) {
            ESP_LOGI(TAG, "Neue Firmware bestaetigt, kein Ruecksprung");
        }
    }
    ESP_LOGI(TAG, "Start abgeschlossen");
}

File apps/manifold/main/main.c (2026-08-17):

/*
 * Ventilsteuerung Fussbodenheizung.
 *
 * Raeume, Kanalzuordnung und Regelparameter sind zur Laufzeit ueber die
 * Weboberflaeche aenderbar.
 */

#include "app_control.h"
#include "app_mqtt.h"
#include "app_ui.h"
#include "app_web.h"
#include "atc_ble.h"
#include "bemf.h"
#include "config_store.h"
#include "i2cbus.h"
#include "esp_app_desc.h"
#include "esp_ota_ops.h"
#include "esp_log.h"
#include "freertos/FreeRTOS.h"
#include "freertos/task.h"
#include "esp_mac.h"
#include "netmgr.h"
#include "peers.h"
#include "sensors_local.h"
#include "sr74hc595.h"

static const char *TAG = "app";

/* Jeder empfangene Messwert wird der Regelung angeboten; sie entscheidet
 * anhand der zugeordneten MAC-Adresse, ob er zu einem Raum gehoert. */
static void on_ble_measurement(const atc_device_t *dev, void *ctx)
{
    (void)ctx;
    control_temperature(dev->mac, dev->temp_c, dev->humidity, dev->battery);
    control_ble_reading(dev->mac, dev->temp_c, dev->humidity, dev->pressure_hpa,
                        dev->battery_mv);
}

void app_main(void)
{
    const esp_app_desc_t *desc = esp_app_get_description();
    ESP_LOGI(TAG, "Ventilsteuerung Fussbodenheizung, Version %s (%s %s)", desc->version,
             desc->date, desc->time);

    ESP_ERROR_CHECK(cfg_init());

    /* Erst die Ausgangsstufe: solange sie nicht steht, darf kein Motor
     * anlaufen. */
    ESP_ERROR_CHECK(sr595_init());
    ESP_ERROR_CHECK(sr595_all_off());

    /* Zeigt beim Start, was am Bus haengt - eine fehlende Anzeige ist sonst
     * nicht von einer falschen Adresse zu unterscheiden. */
    i2cbus_scan();

    ESP_ERROR_CHECK(bemf_start());
    ESP_ERROR_CHECK(control_start());

    /* Fehlende Anzeige oder Fuehler duerfen den Betrieb nicht verhindern -
     * die Regelung ist die Hauptaufgabe. */
    if (sensors_start() != ESP_OK) {
        ESP_LOGW(TAG, "Zusatzsensoren nicht verfuegbar");
    }
    if (ui_start() != ESP_OK) {
        ESP_LOGW(TAG, "Bedienung am Geraet nicht verfuegbar");
    }

    static app_config_t cfg;
    cfg_copy(&cfg);

    netmgr_cfg_t netz;
    cfg_netmgr(&cfg, &netz);
    ESP_ERROR_CHECK(netmgr_start(&netz));
    netmgr_set_reboot_guard(control_busy);
    /* Bluetooth und WLAN teilen sich einen Funkteil. Solange nur der
     * Einrichtungs-Zugangspunkt da ist, gehoert er dem WLAN. */
    netmgr_set_setup_hook(atc_ble_pause);
    ESP_ERROR_CHECK(atc_ble_start(on_ble_measurement, NULL));

    /* Geschwistergeraete im Haus: je Etage eine Platine. Sie melden sich
     * gegenseitig an, damit die Oberflaeche einen Wechsel anbieten kann. */
    uint8_t mac[6] = {0};
    esp_read_mac(mac, ESP_MAC_WIFI_STA);
    char device_id[24];
    snprintf(device_id, sizeof(device_id), "fbh_%02x%02x%02x", mac[3], mac[4], mac[5]);
    if (peers_start(cfg.wifi.hostname, cfg.site, device_id, PEERS_ROLE_MANIFOLD) != ESP_OK) {
        ESP_LOGW(TAG, "Suche nach weiteren Geraeten nicht verfuegbar");
    }
    ESP_ERROR_CHECK(web_start());
    ESP_ERROR_CHECK(mqtt_start());

    /*
     * Der Bootlader haelt eine frisch eingespielte Firmware zunaechst nur auf
     * Probe. Ohne diese Bestaetigung wuerde er beim naechsten Neustart auf die
     * vorherige zurueckrollen. Sie steht bewusst am Ende: bis hierher sind
     * Konfiguration, Ausgangsstufe, Regelung und Weboberflaeche angelaufen.
     */
    const esp_partition_t *running = esp_ota_get_running_partition();
    esp_ota_img_states_t state;
    if (esp_ota_get_state_partition(running, &state) == ESP_OK &&
        state == ESP_OTA_IMG_PENDING_VERIFY) {
        if (esp_ota_mark_app_valid_cancel_rollback() == ESP_OK) {
            ESP_LOGI(TAG, "Neue Firmware bestaetigt, kein Ruecksprung");
        }
    }

    ESP_LOGI(TAG, "Start abgeschlossen");
}

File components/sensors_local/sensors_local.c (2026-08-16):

#include "sensors_local.h"

#include <string.h>

#include "ds18b20.h"
#include "esp_log.h"
#include "freertos/FreeRTOS.h"
#include "freertos/semphr.h"
#include "freertos/task.h"
#include "hw_map.h"
#include "i2cbus.h"
#include "onewire_bus.h"

static const char *TAG = "sens";

#define POLL_PERIOD_MS 30000
#define HDC1080_REG_TEMP 0x00
#define HDC1080_REG_HUM  0x01
#define HDC1080_REG_CFG  0x02

static SemaphoreHandle_t s_mtx;
static sensors_snapshot_t s_snap;

static onewire_bus_handle_t s_bus;
static ds18b20_device_handle_t s_ds[SENSORS_MAX_DS18B20];
static uint8_t s_ds_count;

static i2c_master_dev_handle_t s_hdc;

/* ------------------------------------------------------------------ */
/* DS18B20                                                             */
/* ------------------------------------------------------------------ */

static void ds_discover(void)
{
    onewire_bus_config_t bus_cfg = {.bus_gpio_num = HW_PIN_ONEWIRE};
    onewire_bus_rmt_config_t rmt_cfg = {.max_rx_bytes = 10};

    if (onewire_new_bus_rmt(&bus_cfg, &rmt_cfg, &s_bus) != ESP_OK) {
        ESP_LOGE(TAG, "1-Wire-Bus an GPIO%d liess sich nicht einrichten", HW_PIN_ONEWIRE);
        return;
    }

    onewire_device_iter_handle_t iter = NULL;
    if (onewire_new_device_iter(s_bus, &iter) != ESP_OK) {
        return;
    }

    onewire_device_t dev;
    while (onewire_device_iter_get_next(iter, &dev) == ESP_OK) {
        if (s_ds_count >= SENSORS_MAX_DS18B20) {
            ESP_LOGW(TAG, "Mehr als %d Fuehler am Bus, die weiteren werden ignoriert",
                     SENSORS_MAX_DS18B20);
            break;
        }
        ds18b20_config_t cfg = {};
        ds18b20_device_handle_t handle;
        if (ds18b20_new_device(&dev, &cfg, &handle) != ESP_OK) {
            continue; /* kein DS18B20, etwa ein anderer 1-Wire-Baustein */
        }
        s_ds[s_ds_count] = handle;
        s_snap.ds[s_ds_count].address = dev.address;
        s_ds_count++;
        ESP_LOGI(TAG, "Fuehler 0x%016llX gefunden", dev.address);
    }
    onewire_del_device_iter(iter);

    s_snap.ds_count = s_ds_count;
    ESP_LOGI(TAG, "%u DS18B20 am Bus", s_ds_count);
}

static void ds_read_all(void)
{
    for (uint8_t i = 0; i < s_ds_count; i++) {
        if (ds18b20_trigger_temperature_conversion(s_ds[i]) != ESP_OK) {
            continue;
        }
        float t = 0;
        if (ds18b20_get_temperature(s_ds[i], &t) != ESP_OK) {
            continue;
        }
        /* 85 Grad ist der Ruecksetzwert nach dem Einschalten und kein
         * Messwert. */
        if (t > 84.9f && t < 85.1f) {
            continue;
        }
        xSemaphoreTake(s_mtx, portMAX_DELAY);
        s_snap.ds[i].temp_c = t;
        s_snap.ds[i].valid = true;
        xSemaphoreGive(s_mtx);
    }
}

/* ------------------------------------------------------------------ */
/* HDC1080                                                             */
/* ------------------------------------------------------------------ */

static bool hdc_init(void)
{
    i2c_master_bus_handle_t bus = i2cbus_get();
    if (bus == NULL || !i2cbus_probe(HW_ADDR_HDC1080)) {
        ESP_LOGW(TAG, "Kein HDC1080 auf Adresse 0x%02X", HW_ADDR_HDC1080);
        return false;
    }

    i2c_device_config_t dev = {
        .dev_addr_length = I2C_ADDR_BIT_LEN_7,
        .device_address = HW_ADDR_HDC1080,
        .scl_speed_hz = HW_I2C_FREQ_HZ,
    };
    if (i2c_master_bus_add_device(bus, &dev, &s_hdc) != ESP_OK) {
        return false;
    }

    /* Getrennte Messung, 14 Bit fuer beide Groessen, Heizung aus. */
    uint8_t cfg[3] = {HDC1080_REG_CFG, 0x00, 0x00};
    if (i2c_master_transmit(s_hdc, cfg, sizeof(cfg), 100) != ESP_OK) {
        return false;
    }
    ESP_LOGI(TAG, "HDC1080 bereit");
    return true;
}

/* Der HDC1080 braucht nach dem Anstossen der Messung eine Wandlungszeit,
 * bevor gelesen werden darf. Deshalb Schreiben und Lesen getrennt. */
static bool hdc_read_reg(uint8_t reg, uint16_t *out)
{
    if (i2c_master_transmit(s_hdc, &reg, 1, 100) != ESP_OK) {
        return false;
    }
    vTaskDelay(pdMS_TO_TICKS(20));

    uint8_t raw[2];
    if (i2c_master_receive(s_hdc, raw, sizeof(raw), 100) != ESP_OK) {
        return false;
    }
    *out = (uint16_t)((raw[0] << 8) | raw[1]);
    return true;
}

static void hdc_read(void)
{
    if (s_hdc == NULL) {
        return;
    }
    uint16_t t_raw, h_raw;
    if (!hdc_read_reg(HDC1080_REG_TEMP, &t_raw) || !hdc_read_reg(HDC1080_REG_HUM, &h_raw)) {
        xSemaphoreTake(s_mtx, portMAX_DELAY);
        s_snap.hdc_valid = false;
        xSemaphoreGive(s_mtx);
        return;
    }

    xSemaphoreTake(s_mtx, portMAX_DELAY);
    s_snap.hdc_temp_c = (t_raw / 65536.0f) * 165.0f - 40.0f;
    s_snap.hdc_humidity = (h_raw / 65536.0f) * 100.0f;
    s_snap.hdc_valid = true;
    xSemaphoreGive(s_mtx);
}

/* ------------------------------------------------------------------ */

static void sensors_task(void *arg)
{
    (void)arg;
    for (;;) {
        ds_read_all();
        hdc_read();
        vTaskDelay(pdMS_TO_TICKS(POLL_PERIOD_MS));
    }
}

esp_err_t sensors_start(void)
{
    s_mtx = xSemaphoreCreateMutex();
    if (s_mtx == NULL) {
        return ESP_ERR_NO_MEM;
    }

    ds_discover();
    hdc_init();

    if (s_ds_count == 0 && s_hdc == NULL) {
        ESP_LOGW(TAG, "Keine Zusatzsensoren gefunden, Abfrage wird nicht gestartet");
        return ESP_OK;
    }

    BaseType_t ok = xTaskCreate(sensors_task, "sensors", 4096, NULL, 3, NULL);
    return ok == pdPASS ? ESP_OK : ESP_ERR_NO_MEM;
}

void sensors_get(sensors_snapshot_t *out)
{
    if (s_mtx == NULL) {
        memset(out, 0, sizeof(*out));
        return;
    }
    xSemaphoreTake(s_mtx, portMAX_DELAY);
    *out = s_snap;
    xSemaphoreGive(s_mtx);
}

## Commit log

2026-08-15 Ventilsteuerung Fussbodenheizung auf ESP-IDF
    Ersatz fuer einen HmIP-FALMOT: die HmIP-VDMOT-Stellantriebe bleiben, die
    Steuerung dahinter ist eine eigene Platine mit aufgestecktem ESP32-DevKitC.
    Portierung der bisherigen ESPHome-Konfiguration auf natives ESP-IDF v6.0.2.
    Gegenueber der Vorgaengerfassung:
    - Raeume, Kreiszuordnung, Thermometer und Regelparameter sind zur Laufzeit
    ueber die Weboberflaeche aenderbar statt fest im YAML verdrahtet.
    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
    [partitions.csv]
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2026-08-15 Stack-Ueberlauf und Fehlausloesung der Tasten behoben
    Beim ersten Test auf der Hardware ging das Geraet in eine Neustartschleife.
    Zwei Ursachen, beide nur auf dem Geraet sichtbar:
    1. app_config_t (1484 Byte) und ctl_snapshot_t (1120 Byte) lagen als lokale
    Variablen auf den Task-Stacks. In der Bedien-Task kamen beide zusammen mit
    der Speicherkette zum Sichern der Konfiguration auf 4096 Byte Stack - das
    hat ueberlaufen. Die grossen Kopien liegen jetzt auf dem Heap
    (control, calib) beziehungsweise als statische Puffer in den Tasks, die
    allein darauf zugreifen (ui, mqtt, web). Der ui-Stack ist zusaetzlich auf
    6144 Byte angehoben.
    2. Ausgeloest wurde der Ueberlauf von einer Ge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
    [BOM_steuerung_fussbodenheizung_2026-08-15.csv, PCB_2026-08-15.dxf]
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2026-08-15 Handsteuerung je Kreis, unabhaengig von der geschaetzten Stellung
    Ein gewoehnlicher Fahrbefehl half im Notfall nicht: valve_goto vergleicht die
    geschaetzte Stellung mit dem Ziel und tat nichts, wenn das Ventil bereits als
    offen galt. Bei unbekannter Stellung fuhr "auf" sogar zuerst zu, weil eine
    Referenzfahrt gegen die untere Endlage vorgeschaltet ist.
    valve_force faehrt jetzt ohne Stellungsvergleich bis zum Anschlag; beendet
    wird nur durch Endlage, Maximallaufzeit oder Halt. Der Kreis bleibt danach im
    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
    [fbh_deckel.stl, fbh_displayrahmen.stl, fbh_gehaeuse.step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]
2026-08-15 Sollwert als Zahl eingebbar, README überarbeitet
    Die Solltemperatur liess sich nur in Halbgradschritten ueber die beiden
    Schaltflaechen verstellen. Sie steht jetzt zusaetzlich als Eingabefeld in der
    Raumkarte; die Schaltflaechen bleiben. Waehrend der Eingabe setzt der
    Abfragetakt das Neuzeichnen der Karten aus, sonst waere die Eingabe nach
    spaetestens einer Sekunde ueberschrieben. Werte ausserhalb 5 bis 35 Grad
    werden abgewiesen, bevor sie ans Geraet gehen.
    Die README ist durchgesehen und gegen den Quelltext abgeglichen. Korrigiert
    wurden unter anderem die Zahl der Pruefungen, die Groesse der Oberflaeche, der
    Umfang der Home-Assistant-Entities und die Beschreibung des Handbetriebs.
    Entfern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
2026-08-15 Integration fuer Home Assistant, README nach ueblichen Konventionen
    Bisher lief die Anbindung ausschliesslich ueber MQTT-Discovery, was einen
    Broker voraussetzt. Die Integration unter custom_components/floor_heating
    spricht unmittelbar mit dem Geraet: Einrichtung ueber die Adresse, danach
    Thermostat je Raum, Ventil je Kreis, Messwerte, Zustandsmelder und
    Schaltflaechen. Dazu fuenf Dienste fuer Messfahrt, Notfahrt und das Aufheben
    des Handbetriebs - Vorgaenge, die sich ueber MQTT nur umstaendlich abbilden
    lassen.
    Der Zustand wird alle fuenf Sekunden abgefragt und nutzt den
    Aenderungszaehler des Geraets als ETag; im Ruhezustand bleibt die Antwort
    ohne Inhalt.
    /api/state liefert dafuer neu ei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
2026-08-16 Konzept fuer die Anbindung von Kessel, Pufferspeicher und Heizkreispumpen
    Zwei weitere ESP32 erfassen die Temperaturen an Oelkessel und Pufferspeicher.
    Aus Abgas- und Kesselwerten wird der Brennerlauf und der Ladefortschritt
    erkannt; die beiden Heizkreispumpen werden ueber ein Tasmota-Relais
    abgeschaltet, solange kein Ventil offen ist. Den Bedarf holen sich die Geraete
    unmittelbar von den Verteilerplatinen, ohne Broker und ohne Home Assistant.
    Das Repository nimmt dafuer eine zweite Anwendung auf. Der Umbau ist getrennt
    beschrieben, samt Nachweis, dass das Abbild der Verteiler-Firmware dabei
    unveraendert bleibt.
2026-08-16 Verteiler-Firmware nach apps/manifold verschoben
    Vorbereitung fuer die zweite Anwendung: components/ bleibt in der Wurzel und
    wird kuenftig geteilt, die Anwendung zieht mit ihrer Projektdatei,
    Partitionstabelle und Abhaengigkeitsliste nach apps/manifold. Gebaut wird ab
    jetzt mit "idf.py -C apps/manifold build".
    ESP-IDF bildet fuer __FILE__ nur die Projektwurzel auf "." ab. Da die
    Komponenten seit dem Umzug ausserhalb davon liegen, kommt eine zweite Abbildung
    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
    [partitions.csv]
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2026-08-16 Waermeerzeuger: Fuehlererfassung, Anlagenschema und Verlauf
    Erste Stufe der Heizungsanbindung. Dieselbe Firmware laeuft auf beiden
    Geraeten -- am Kessel mit drei Fuehlern, am Pufferspeicher mit fuenf. Welche
    Aufgabe eines uebernimmt, ergibt sich allein aus den zugeordneten Rollen;
    einen Rollenschalter gibt es nicht.
    Neue gemeinsame Komponente onewire_temp: mehrere DS18B20 an bis zu zwei
    Bussen, Pins als Parameter. Gewandelt wird per Sammelbefehl statt je Fuehler
    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
    [partitions.csv]
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2026-08-16 Stufe 2: Bedarf der Verteiler abfragen und die Pumpen schalten
    Der Verteiler bekommt /api/demand: eine schlanke Auskunft, ob an ihm Waerme
    gebraucht wird. Bedarf besteht, sobald bei einem Kanal die groessere von Ist-
    und Zielstellung ueber 5 Prozent liegt -- die Zielstellung geht mit ein, damit
    die Pumpe nicht erst vierzig Sekunden spaeter anlaeuft, wenn das Ventil offen
    ist.
    Das Heizungsgeraet findet die Verteiler ueber mDNS und fragt sie selbst ab.
    Ein Broker ist dafuer nicht noetig. Ein Verteiler, der frueher geantwortet hat
    und jetzt schweigt, gilt als bedarfsmeldend; einer, der seit dem Start nie
    geantwortet hat, wird nicht gewertet -- sonst liefe die Pumpe wegen eines
    dauerhaft abgesc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
    [main.c]
2026-08-16 Relais auch ohne Broker schalten, Zahl der Heizkreise nicht mehr festgelegt
    Ist kein MQTT-Broker eingerichtet, geht der Befehl unmittelbar an die
    Tasmota-Schnittstelle /cm. Die Antwort traegt den tatsaechlichen Zustand des
    Relais und ersetzt damit die Rueckmeldung, die ueber MQTT von selbst kaeme;
    zwischen zwei Aufrufen bleibt eine Aenderung am Relais unbemerkt, deshalb wird
    der Sollzustand zyklisch nachgesendet. Verlangt das Relais eine Anmeldung,
    werden Benutzer und Kennwort angehaengt. Erfolglose Versuche werden nicht mehr
    im Sekundentakt wiederholt -- die Aufgabe stand dabei jedes Mal zwei Sekunden
    im Zeitablauf.
    Die Oberflaeche weist aus, ueber welchen Weg geschaltet wird, und
    untersch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
2026-08-16 Netzsuche nebenlaeufig, gemeinsames Stilblatt
    Die Suche nach WLAN-Netzen meldete "load failed". Sie lief blockierend: das
    Funkteil geht dabei die Kanaele durch, der eigene Zugangspunkt ist so lange
    nicht erreichbar -- und genau ueber ihn lief die Anfrage. Im
    Zugangspunkt-Betrieb ist das der einzige Weg zum Geraet, die Suche konnte also
    gar nicht gelingen. Sie laeuft jetzt nebenlaeufig: POST stoesst an, GET holt
    den Stand, und die Oberflaeche wiederholt eine gescheiterte Abfrage, statt sie
    als Fehler zu werten.
    Das gemeinsame Geruest beider Oberflaechen steht in www/stil.css: Farben,
    Schriften, Radien, die Grundregeln und der Aufbau aus Kopfzeile, Reitern und
    Inhaltsflaeche. Geteilt wird bew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
2026-08-16 Heizkreise anlegen und loeschen, Aufzeichnung schaltet sich selbst scharf
    Angelegt werden konnte nur ein einziger Heizkreis: die Schaltflaeche stand in
    der Karte "Keine Heizkreise angelegt", und die verschwand mit dem ersten
    Kreis. Loeschen ging gar nicht. Beides steht jetzt dort, wo man es sucht --
    das Anlegen am Ende der Liste, mit der Angabe, wie viele der vier Kreise
    belegt sind und welche Fuehlerrollen der naechste bekommt; das Loeschen am
    Fuss jeder Karte.
    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
    [fbh_deckel.stl, fbh_deckel_ohne_display.stl, fbh_displayrahmen.stl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]
2026-08-16 Fuehlerzuordnung aus der Konfiguration zeichnen, nicht aus dem Zustand
    Nach dem Speichern sprang die Auswahl noch einmal auf "nicht zugeordnet"
    zurueck, obwohl gespeichert war; erst ein Neuladen zeigte die Zuordnung.
    Die Tabelle nahm die Rolle aus /api/state. Der Zustand folgt einer Aenderung
    aber erst mit der naechsten Leserunde: am Geraet gemessen ist die Antwort auf
    das Speichern nach 52 ms da, der Zustand zieht nach 717 ms nach. Die
    Oberflaeche zeichnet unmittelbar nach dem Speichern neu und traf damit genau
    das Zeitfenster, in dem der Zustand die alte Zuordnung meldet -- und blieb
    dabei bis zur naechsten Abfrage fuenf Sekunden spaeter.
    Zustaendig ist ohnehin die Konfiguration: sie sag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
2026-08-16 Lizenz auf GPL-3.0, Herkunft benannt
    Das Projekt lag unter Apache-2.0 und nannte keine Vorlage. Es ist aber die
    Portierung eines ESPHome-Aufbaus, und der geht auf floor-heating-controller
    von nliaudat zurueck -- eine ESPHome-Konfiguration fuer dessen Shield
    esp32_8ch_motor_shield. Der Bestand sagt das an mehreren Stellen selbst:
    main.c nennt die Portierung, roomctrl das uebernommene Regelgesetz,
    app_control die uebernommene Anlaufzeit.
    Die Vorlage steht unter der GPL-3.0. Apache-2.0 und GPL-3.0 vertragen sich nur
    in eine Richtung: Apache-Code darf in ein GPL-Projekt, umgekehrt nicht. Der
    Bestand folgt der Vorlage deshalb in der Lizenz.
    Die eingebundenen Fremdkomponenten stehen unter MIT un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
2026-08-16 Platinendaten unter CERN-OHL-S 2.0
    Die GPL passt fuer Entwurfsdaten einer Leiterplatte nicht. Ihre
    Rueckgabepflicht haengt am Weitergeben von Objektcode, und eine gefertigte
    Leiterplatte ist keine Kopie der Entwurfszeichnung -- die Pflicht liefe genau
    dort ins Leere, wo sie gemeint ist. Wer die Platine fertigt und verkauft,
    muesste nichts zurueckgeben. Dazu kommt Maschinerie, die fuer eine Platine
    bedeutungslos ist: Corresponding Source, Installationsinformationen,
    Systembibliotheken.
    Die CERN Open Hardware Licence knuepft dieselbe Pflicht an das Bereitstellen
    des Produkts und deckt Rechte ab, die ueber das Urheberrecht hinausgehen --
    sie sagt deshalb "reziprok" statt "copyleft". board/ ste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
2026-08-16 Woechentliche Schutzfahrt der Ventile, Schutzlauf der Pumpen am Termin
    Im Sommer stehen die Ventile ueber Monate geschlossen. Einmal in der Woche
    faehrt jetzt jeder Kreis auf Anschlag auf, wieder zu und danach auf seine
    vorherige Stellung zurueck. Gefahren wird auf Anschlag statt auf eine
    Stellung: die Fahrt soll den ganzen Weg abdecken, und die Stellung ist danach
    wieder gesichert statt geschaetzt.
    Uebergangen wird, wer seit der letzten Schutzfahrt ohnehin gefahren ist -- wer
    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
    [fbh_deckel_ohne_display_randclips.stl, fbh_deckel_ohne_display_schnapper.stl, fbh_deckel_randclips.stl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]
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2026-08-16 Brennerzustand vom Kessel auch am Speicherboard anzeigen
    Die Karte "Brenner" am Pufferspeicher meldete "unbekannt", waehrend die
    Aufzeichnung daneben "loest ueber den Brennerzustand aus" schrieb. Beides
    stimmte fuer sich -- die Karte zeigte die eigene Erkennung, die es ohne
    Abgasfuehler nicht gibt, die Aufzeichnung nahm die vom Kessel. Nebeneinander
    las sich das widerspruechlich.
    burner_get liefert jetzt den Zustand, der tatsaechlich gilt: eigener
    Abgasfuehler, sonst das Geraet am Kessel, mit einem Vermerk woher. Die
    Tageswerte bleiben die eigenen und damit null -- gezaehlt wird dort, wo
    gemessen wird, und die Karte sagt das auch. Abgaswert und Bezugslinie
    entfallen in dem Fall aus der eige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
2026-08-16 Gehaeuse: Stuetzung unter der Buchsenreihe, Deckelschrauben auf M2,5
    Die vier Befestigungsbohrungen der Platine liegen alle in der oberen Haelfte,
    Y 46,9 bis 87,5. Unter der RJ11-Reihe stuetzte nichts -- und dort wird elfmal
    ein Stecker hineingedrueckt, auf 47 mm freier Laenge. Dazu kommen jetzt elf
    Pads Ø6,0 auf den Buchsenmitten und eine durchgehende Querrippe bei Y 15 bis
    18. Die freie Laenge sinkt damit auf 28,9 mm.
    Wo gestuetzt werden darf, ist gerechnet und nicht ausgesucht: die Unterseite
    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
    [fbh_deckel.stl, fbh_deckel_ohne_display.stl, fbh_deckel_ohne_display_randclips.stl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]
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2026-08-17 Kesselkreispumpe als Rechenmodul
    Der Kessel gibt nur dann Waerme ab, wenn sein Vorlauf waermer ist als das, was
    aus dem Speicher zurueckkommt. Kehrt sich das um -- der Brenner ist aus, der
    Kessel kuehlt aus --, foerdert dieselbe Pumpe Waerme aus dem Speicher in den
    Kessel, und von dort geht sie durch den Schornstein verloren.
    Zweipunktverhalten mit Haltezeit, dazu Mindestlaufzeit und Mindestpause. Zwei
    Regeln gehen der Spreizung vor: Ohne gueltige Messwerte laeuft die Pumpe, und
    ueber der Notgrenze ebenfalls. Eine laufende Pumpe ohne Not ist
    verschwenderisch, ein heisser Kessel ohne Abfuhr ist es nicht.
    Der Brennerzustand geht bewusst nicht ein. Die Spreizung sagt dasselbe, nur
    eine Stufe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
2026-08-17 Kesselkreispumpe im Geraet, Rollen sauber getrennt
    Die Pumpe wird am Ende der Pumpenauswertung gefahren, mit Werten aus
    sensors_role_value -- also nur aus eigenen Fuehlern, nicht ueber any_role_value
    aus dem Netz. relay_t ist dafuer aus circuit_t herausgeloest, damit push_relay
    und http_cmd beide Faelle bedienen.
    Dazu zwei Pruefungen, die dieselbe Trennung erzwingen:
    Die Kesselkreispumpe braucht Kesselvor- und -ruecklauf an diesem Geraet. Mit
    Werten vom Nachbargeraet zu schalten waere eine Entscheidung ohne eigene
    Grundlage -- und schlimmer: Faellt die Verbindung aus, gilt "keine Messwerte",
    und die Fail-Safe-Regel liesse die Pumpe dauerhaft laufen.
    Heizkreise brauchen den Pufferfuehler a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
2026-08-17 Handbuch und README auf den Stand der Anlage
    Vier Geraete statt drei, 483 Pruefungen statt 297, neun der 22 Kreise
    vermessen. Neu beschrieben sind Kesselkreispumpe, Verbrauchslinie,
    Abgas-Vorlauf-Abstand, Befunde und die Sicherung der Einstellungen.
    Richtiggestellt: Der Weg der Aussentemperatur ist nicht mehr die Bedarfsabfrage
    alle fuenf Sekunden, sondern eine eigene Abfrage je Minute an eine beliebige
    Verteilerplatine. Und die Sicherung ueber GET /api/config war nie eine: Dort
    stehen keine Kennwoerter.
    "Ausschalten" heisst jetzt, dass die Ventile zufahren -- der Abschnitt sagte
    bisher das Gegenteil.
    Aus den geplanten Erweiterungen faellt der Heizungsbereich heraus; er laeuft.
    Uebrig ble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
2026-08-17 Gehaeuseschale: Schnapper ueberarbeitet
    [fussbodenheizung-schale-schnapper.3mf]
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2026-08-18 Scharfe Aufzeichnung uebersteht den Neustart
    Sie wartet womoeglich stundenlang auf die naechste Ladung. Bisher stand der
    Zustand nur im Arbeitsspeicher, und jeder Neustart verwarf ihn -- daran ist die
    erste Ladung dieser Anlage vorbeigelaufen, weil an dem Tag mehrfach Firmware
    aufgespielt wurde.
    Gemerkt wird nur das Scharfsein, nicht der Inhalt: Der liegt im
    Arbeitsspeicher und ist nach einem Neustart ohnehin weg. Beim Start wird
    deshalb neu aufgesetzt, und zwar aus der Brenner-Task heraus statt aus
    burner_start -- der Puffer richtet sich nach den vorhandenen Messstellen, und
    die stehen erst, wenn die Fuehlererfassung einmal durchgelaufen ist.
    Verbraucht ist das Scharfsein, sobald eine Lad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
2026-09-21 Kesselkreispumpe: Grund nennt den Vergleich mit dem Speicher
    Stand die Pumpe, meldete sie "Ruecklauf waermer als Vorlauf" -- die Regel
    bis zum 18. August. Seitdem wird der Kesselvorlauf mit dem Speicher
    verglichen, und gerade bei stehender Pumpe sagt der Ruecklauf nichts mehr:
    Vor- und Ruecklauf nehmen dann die Temperatur des Kesselkoerpers an. Der Text
    nannte als Grund also etwas, das die Regelung laengst nicht mehr prueft.
    Jetzt: "Kessel kaum waermer als der Speicher", in der Oberflaeche mit dem
    Zusatz, dass Foerdern keine Waerme in den Speicher braechte. Die Kennung
    no_transfer bleibt; die Home-Assistant-Integration merkt davon nichts.
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2026-10-03 Leitstand mit Protokoll und HomeKit, App, Brennerregel der Kesselkreispumpe
    Stand seit v0.4.0; Einzelheiten in CHANGELOG.md.
    Neues Geraet unter apps/station: ein M5Stack Core als Leitstand. Er fragt
    Heizungsgeraete und Verteiler ab, empfaengt Funkthermometer, liefert die
    Aussentemperatur und schreibt ein Protokoll auf die SD-Karte
    (components/protokoll, Spalten nach docs/katalog-messgroessen.md). Am Core2
    kommen sechs Seiten mit Beruehrung, die Echtzeituhr und eine HomeKit-Bruecke
    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
    [partitions.csv, speicher-log-charges.csv, speicher-log-days.csv]
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2026-11-02 Einstellungen: verstaendliche Bezeichnungen und Hinweistexte
    "Haltezeit aus" der Brennererkennung wurde fuer den Nachlauf der
    Kesselkreispumpe gehalten und auf 1800 s gestellt. Die Einstellung
    verschiebt aber das erkannte Brennerende: 25 Minuten und rund 0,9 l Oel
    je Lauf zu viel, und der Nachlauf beginnt entsprechend spaeter.
    Das Wort "Haltezeit" ist weg, "Nachlauf" hat in beiden Faellen einen
    Zusatz. Jeder Hinweistext sagt, was die Einstellung an der Anlage
    bewirkt, was ein hoeherer oder niedrigerer Wert zur Folge hat und wo
    die verwechselbare Einstellung steht. App, die drei Weboberflaechen und
    das Handbuch verwenden dieselben Namen. Die Weboberflaechen haben jetzt
    "Erweitert" und je Abs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
